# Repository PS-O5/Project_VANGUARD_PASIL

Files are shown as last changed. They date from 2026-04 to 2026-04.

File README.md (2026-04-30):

# VANGUARD-PASIL

**Flight Control Architecture & Integration**  
*Document Revision: E (Production-Ready)*

VANGUARD-PASIL is a real-time, safety-critical flight control testbed that bridges human pilot commands to physical motor actuation. Built on Apache NuttX 12.13.0, this platform evolves from a custom bare-metal kernel to a fully telemetric split-architecture system. 

## 🚀 Key Features

* **Deterministic Control Loop:** Runs a single high-priority thread (255) at 500 Hz ($\Delta t=0.002~s$) for consistent execution.
* **CMSIS-DSP Acceleration:** Hardware FPU acceleration computes a 7x7 Extended Kalman Filter (EKF) to maintain optimal attitude and gyro bias estimates.
* **Multi-Stage Failsafe:** Safety-critical protection forces zero throttle and attitude levelling upon RF link loss, transitioning to a hard lock/motor stop after 2 seconds of lost connection.
* **Clean Power Architecture:** Utilizes a star-ground topology and isolated regulators (including a dedicated ultra-low-noise 3.3V LDO for the RF module) to prevent ESC noise from causing brownouts.
* **Application-Level Sensor Management:** Custom I2C management bypasses kernel conflicts, including forced-mode polling for the BMP280 barometer.

## 🛠️ Hardware Stack

### Flight Controller (Airborne)
* **MCU:** STM32F411CEU6 "BlackPill" @ 100 MHz.
* **IMU:** BMI160.
* **Magnetometer:** QMC5883P.
* **Barometer:** BMP280.
* **Time of Flight (ToF):** VL53L0X.
* **Actuation:** 4x ESCs driven via deterministic 50 Hz hardware PWM (TIM2/TIM3).

### Ground Control Station (GCS)
* **MCU:** ESP32 DevKit (Dual-core Xtensa LX6 @ 240 MHz).
* **Inputs:** 2x Hall-effect joysticks on ADC1.
* **Display:** 2.4" SPI ILI9341 TFT.

### Telemetry Link
* **Module:** Full-duplex NRF24L01+PA+LNA (2.4 GHz).
* **Performance:** 2 Mbps air data rate with Auto-ACK enabled.

## ⚙️ Build & Recovery Instructions

1. **Clean Build:** Execute `make clean` after any Kconfig changes.
2. **FPU:** Ensure `CONFIG_LIBC_FLOATINGPOINT=y` is enabled.
3. **Sensors:** Disable all kernel sensor drivers except the BMI160.
4. **CMSIS:** Verify the Board Makefile lists required CMSIS source files.
5. **Failsafe Tuning:** Timeout constants are configurable in `pasil_ekf.h`.

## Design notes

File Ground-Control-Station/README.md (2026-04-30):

# VANGUARD-PASIL Ground Control Station (GCS)

The Ground Control Station (GCS) is a split-architecture counterpart to the VANGUARD-PASIL Flight Controller. It reads pilot inputs via Hall-effect joysticks, transmits telemetry via a 2.4 GHz RF link, and displays real-time flight data on a 2.4" TFT screen without blocking critical transmission loops.

## 💻 Hardware Overview

* **Microcontroller:** ESP32 DevKit (Xtensa LX6 @ 240 MHz).
* **Telemetry:** NRF24L01+PA+LNA operating at 2 Mbps.
* **Display:** 2.4" SPI ILI9341 TFT Display.
* **Inputs:** 2x Hall-effect joysticks read via ADC1.
* **OS:** FreeRTOS (dedicated task drives the TFT at 20 Hz).

## 🔧 TFT_eSPI Configuration (`User_Setup.h`)

To ensure the `TFT_eSPI` library interfaces correctly with the 2.4" ILI9341 display driven by the ESP32[cite: 1], you must modify your `User_Setup.h` (or custom user config file) as follows. 

Comment out the default driver and strictly define the ILI9341 alongside standard ESP32 VSPI hardware pins.
```cpp
// ================================================================
// VANGUARD-PASIL GCS - TFT_eSPI Configuration
// ================================================================

// 1. Define the specific display driver
#define ILI9341_DRIVER       // Select the ILI9341 driver

// 2. Define the ESP32 VSPI Pins
// (Adjust these if your custom GCS schematic routes SPI differently)
#define TFT_MISO 19
#define TFT_MOSI 23
#define TFT_SCLK 18
#define TFT_CS    5  // Chip select control pin
#define TFT_DC    2  // Data Command control pin
#define TFT_RST   4  // Reset pin (could connect to RST pin)

// 3. Fonts (Optional but recommended for GCS UI)
#define LOAD_GLCD   // Font 1. Original Adafruit 8 pixel font needs ~1820 bytes in FLASH
#define LOAD_FONT2  // Font 2. Small 16 pixel high font
#define LOAD_FONT4  // Font 4. Medium 26 pixel high font

// 4. SPI Frequency (Optimised for FreeRTOS 20Hz update rate)
#define SPI_FREQUENCY  40000000
```

## 📡 RF Payload Structure

The ESP32 transmits a packed 32-byte binary payload via the NRF24L01:

16 bytes: 4 floats (Roll, Pitch, Yaw, Throttle).

1 byte: Arming state.

1 byte: Sequence counter.

2 bytes: CRC-16 (CCITT).

12 bytes: Reserved for future telemetry expansions.

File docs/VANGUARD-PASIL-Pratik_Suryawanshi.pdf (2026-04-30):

# VANGUARD-PASIL

## Flight Control Architecture & Integration Report

Phases 1–7: From Bare Metal to Telemetric Control

Production-Ready: Failsafe, Empirical Data, Power Architecture

Document ID: VANGUARD-PASIL-005 | Revision: E (Final Gate Review)

Pratik Suryawanshi

pratik.suryawanshi@uni-bayreuth.de

April 30, 2026

Abstract

This comprehensive Hardware-Software Interface (HSI) report documents the VANGUARD-PASIL flight control stack from a bare-metal kernel to a fully telemetric split-architecture system. The platform runs Apache NuttX 12.13 on an STM32F411CEU6 (BlackPill) as the airborne Flight Controller (FC), coupled with an ESP32 Ground Control Station (GCS) over a 2.4 GHz NRF24L01+PA+LNA RF link. This revision addresses production-critical gaps: a multi-stage failsafe mechanism that forces zero throttle and attitude levelling upon link loss, empirical loop timing and PID step response plots, a detailed power distribution architecture isolating noisy ESCs from avionics, and traceability via actual Git commit hashes for each development phase. The document is presented for formal design gate review.

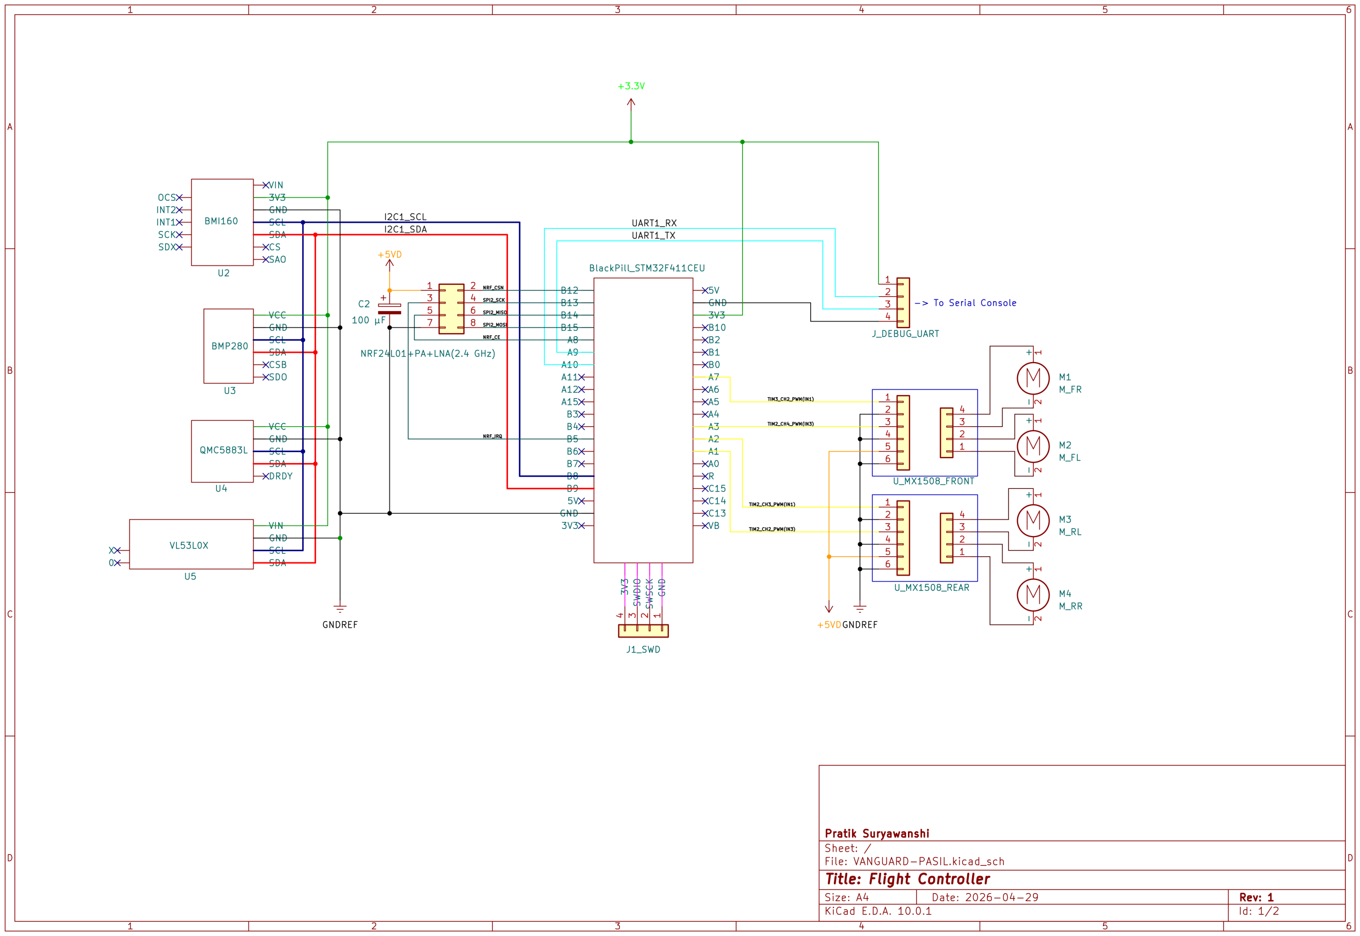
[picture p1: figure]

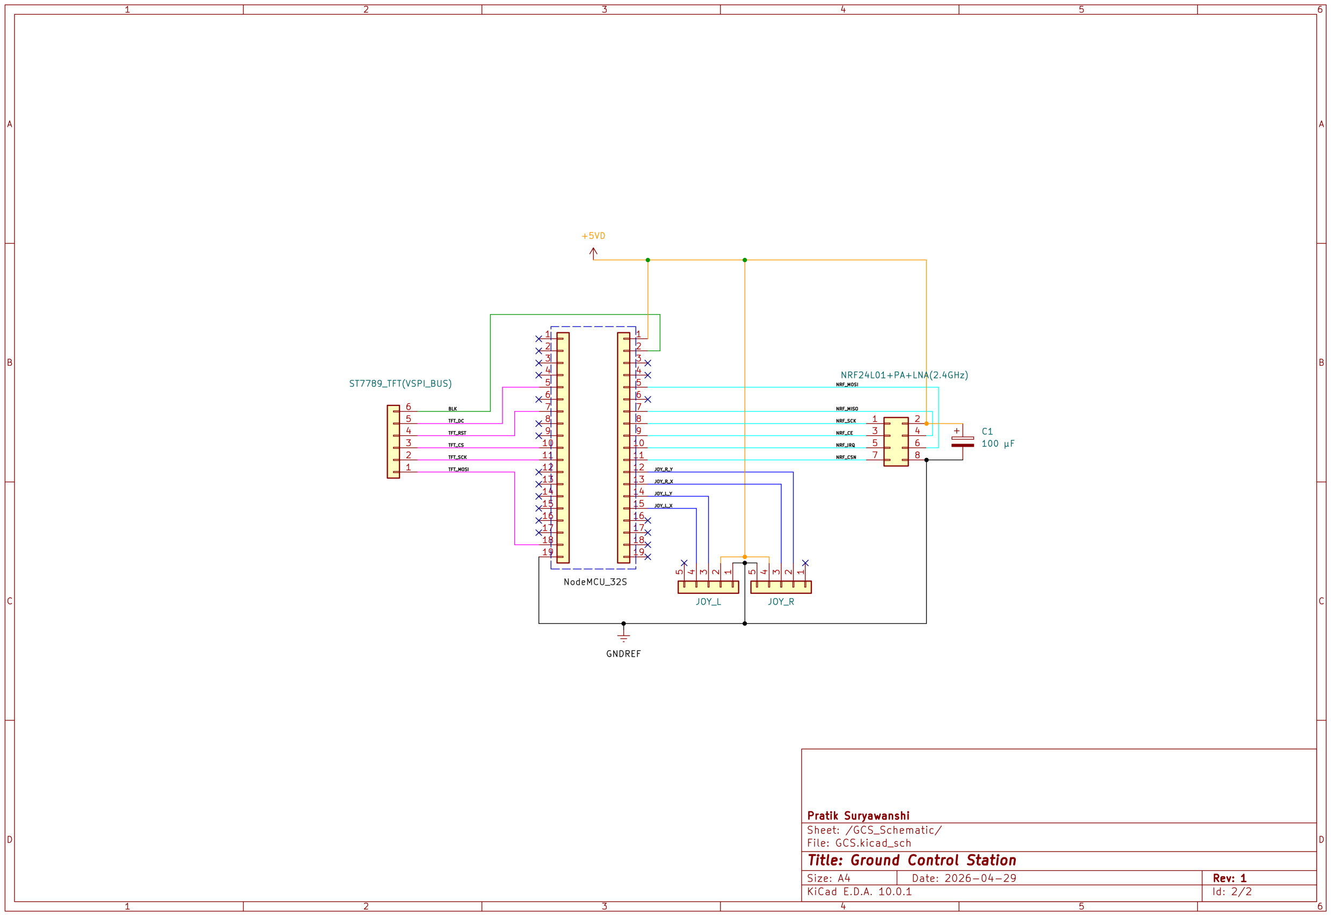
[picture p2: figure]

VANGUARD-PASIL – Production Flight Control Report | 4
Revision Date | Author | Description
A | 2026-04-25 | P. Suryawanshi | Phases 1 & 2 initial report.
B | 2026-04-26 | P. Suryawanshi | Added Phases 3–5, theoretical foundations.
C | 2026-04-27 | P. Suryawanshi | Integrated after-action sensor battles, telemetry specs.
D | 2026-04-28 | P. Suryawanshi | Added Phases 6 & 7: iron bird, GCS, rate PID, motor mixer.
E | April 30, 2026 | P. Suryawanshi | Production readiness: failsafe rework, empirical data, power arch., Git commits.

VANGUARD-PASIL – Production Flight Control Report | 5

## Contents

1 Executive Summary | 6
2 System Architecture Overview | 6
3 Theoretical Foundations | 7
4 Phase 1: RTOS Baseline & Memory Architecture | 8
5 Phase 2: Sensor Fleet Integration & the I2C Wars | 8
6 Phase 3: Hardware FPU & EKF Engine Integration | 9
7 Phase 4: Deterministic PWM Actuation | 9
8 Phase 5: Closed-Loop Kinematic Bridge | 9
9 Phase 6: Sensor Ratification & Iron Bird Actuation | 9
10 Phase 7: Split-Architecture Ground Control Station (GCS) | 9
11 Empirical Validation & Performance Metrics | 10
12 Build & Recovery Instructions | 11
13 Conclusion & Future Work | 12
A Git Commit Traceability | 12

VANGUARD-PASIL – Production Flight Control Report | 6

## 1 Executive Summary

The VANGUARD-PASIL project establishes a real-time, safety-critical flight control testbed capable of bridging human pilot commands to physical motor actuation. Starting from a bare-metal Apache NuttX 12.13 baseline on the STM32F411CEU6 “BlackPill”, the system has evolved through seven phases:

- Phase 1: Custom kernel with 121 KB free heap and robust logging.
- Phase 2: Physical validation of a 4-sensor I2C daisy chain and resolution of every sensor-specific firmware conflict.
- Phase 3: Integration of CMSIS-DSP to accelerate a 7×7 Extended Kalman Filter at 500 Hz.
- Phase 4: Deterministic 50 Hz hardware PWM generation on TIM2 after defeating hardware traps and linker blockades.
- Phase 5: Closed-loop attitude control: IMU → EKF → PID → PWM.
- Phase 6: Sensor ratification and successful ESC arming protocol (1000 µs zero-throttle pulse).
- Phase 7: Introduction of an ESP32 Ground Control Station reading Hall Effect joysticks and transmitting commands via an NRF24L01 2 Mbps RF link, with rate PID and Quad-X motor mixing on the FC.

All design choices are justified with the underlying physics and firmware logic, making this report a complete reference for safety-critical drone development.

## 2 System Architecture Overview

The VANGUARD-PASIL platform employs a split-architecture paradigm:

- Flight Controller (FC): STM32F411CEU6 (BlackPill) @ 100 MHz, running Apache NuttX 12.13.0. Sensors: BMI160 IMU, QMC5883P magnetometer, BMP280 barometer, VL53L0X ToF laser, all on I2C1. Actuators: 4× ESCs on TIM2/TIM3 PWM outputs (PA1, PA2, PA3, PA4 — see Table 1).
- Ground Control Station (GCS): ESP32 DevKit, dual-core Xtensa LX6 @ 240 MHz, reading 2× Hall-effect joysticks (ADC) and driving a 2.4" SPI ILI9341 TFT display.
- Telemetry Link: Full-duplex NRF24L01+PA+LNA modules, 2.4 GHz, 2 Mbps air data rate, Auto-ACK enabled.

The FC runs a single high-priority thread (255) at 500 Hz that ingests sensor data, executes the EKF, processes pilot commands, runs the PID controller, mixes motor outputs, and updates PWM registers.

### 2.1 Power Distribution Architecture

To isolate noisy motor rails from sensitive digital and RF circuits, the following power tree is implemented:

- A 3S LiPo (11.1 V) feeds the main Power Distribution Board (PDB), which directly powers the four ESCs.
- A switching step-down regulator (Mini-560, 5 V / 3 A) provides a primary 5 V rail for the ESP32 and the STM32 BlackPill (which contains its own 3.3 V LDO).
- A dedicated ultra-low-noise 3.3 V LDO (AMS1117-3.3 with 100 µF tantalum and 0.1 µF ceramic capacitors) supplies solely the NRF24L01+PA+LNA module. This prevents transmit current spikes (up to 115 mA) from causing brownouts on the main 3.3 V rail.
- A star-ground topology isolates the digital ground plane (STM32, ESP32, RF module) from the ESC high-current return path, minimising conducted EMI.

All I2C and SPI signal cables are kept shorter than 10 cm and twisted with ground wires.

VANGUARD-PASIL – Production Flight Control Report | 7

### 2.2 Motor PWM Pin Assignment

Table 1 lists the hardware timer channels and corresponding GPIO pins used to drive the four ESCs. All outputs are 50 Hz, 1000–2000 µs, generated atomically via preload.

Table 1: Motor PWM Pin Mapping

Motor | Timer Channel GPIO Label
Front-Left (M1) | TIM2_CH2 | PA1 | ESC_FL
Front-Right (M2) TIM2_CH3 | PA2 | ESC_FR
Rear-Left (M3) | TIM2_CH4 | PA3 | ESC_RL
Rear-Right (M4) | TIM3_CH2 | PA4 | ESC_RR

## 3 Theoretical Foundations

All control and estimation algorithms are executed at a deterministic rate of 500 Hz (∆t = 0.002 s) within the highest-priority NuttX thread.

### 3.1 Extended Kalman Filter (EKF) Covariance Update

The EKF fuses the 3-axis accelerometer and gyroscope data from the BMI160 to maintain an optimal estimate of the attitude quaternion and gyro biases (7-state vector). The a priori error covariance matrix P is propagated as:

Pk|k−1 = FkPk−1|k−1F

T
k + Qk | (1)

where:

- Fk ∈ R

7×7
is the state transition Jacobian derived from the current angular velocity ω.
- Qk ∈ R

7×7
is the process noise covariance matrix, tuned from IMU Allan variance characterization.

The FkP FT
k

product is accelerated using CMSIS-DSP’s arm_mat_mult_f32, which exploits Cortex-M4F SIMD instructions.

### 3.2 Discrete-Time Rate PID Controller

Pilot commands are interpreted as target body angular rates Ωtarget = [ptarget, qtarget, rtarget]

T
. The
EKF outputs the current estimated rates Ωcurrent. The error vector ⃗e(t) = Ωtarget − Ωcurrent drives a parallel set of discrete PID controllers:

u(t) = Kpe(t) + Ki

Xn

k=0

e(k∆t)∆t + Kd

e(t) − e(t − ∆t)
∆t

(2)

Integrator anti-windup is applied via conditional integration clamping.

### 3.3 Quad-X Motor Mixing Matrix

The PID torque outputs uroll, upitch, uyaw and the normalised throttle command T (0–1) are distributed to the four motors using the standard Quad-X mixing matrix:

MF L

MF R

MBL

MBR

=

1 | 1 | 1 | −1
1 −1 | 1 | 1
1 | 1 | −1 | 1
1 −1 −1 | 1

T

uroll

upitch

uyaw

(3)

VANGUARD-PASIL – Production Flight Control Report | 8

Each motor command Mi

is linearly mapped to a PWM pulse width: CCRi = 1000 + (Mi/2) × 1000, ensuring values in the 1000–2000 µs range.

## 4 Phase 1: RTOS Baseline & Memory Architecture

### 4.1 Out-of-Tree Build and Heap Optimization

A custom board directory custom_boards/blackpill-f411 is linked via Git submodules, keeping a clean history. Aggressive defconfig pruning removed unused subsystems, leaving 121 KB of free heap after boot (out of 128 KB total SRAM).
The silent boot (no console messages) was resolved by adding CONFIG_BOARD_LATE_INITIALIZE, CONFIG_SYSLOG_CHAR, and CONFIG_NSH_SYSLOG to the defconfig. To guarantee /proc availability, mount(NULL, "/proc", "procfs", 0, NULL) is called directly inside board_app_initialize().

## 5 Phase 2: Sensor Fleet Integration & the I2C Wars

The 4-sensor I2C1 bus (PB8-SCL, PB9-SDA at 400 kHz) was scanned with the NuttX i2c tool after a make clean. The physical addresses were found to deviate from datasheet defaults:

Table 2: Physical I2C Address Map

7-bit Address Device | Deviation
0x69 | BMI160 IMU | SDO pulled HIGH (default 0x68)
0x2C | QMC5883P Magnetometer | Advertised as HMC5883L (0x1E); completely different register map
0x76 | BMP280 Barometer | Alternate address (SDO LOW)
0x29 | VL53L0X ToF | Standard ST address

### 5.1 Magnetometer (QMC5883P)

The sensor was stimulated in continuous mode (write 0x01 to 0x09), and multi-byte reads start at 0x01 (X-axis LSB). Local variable scopes were changed to static to prevent the “zero trap” caused by reinitialization before slow I2C transfers completed.

### 5.2 VL53L0X Fortress Strategy

The STMicroelectronics API caused POSIX type clashes (uint32_t redefinition) and linker errors (VL53L0X_PollingDelay missing). The solution:

- Replace vl53l0x_types.h with a minimal header including <stdint.h> and the critical FixPoint1616_t typedef.
- Create vl53l0x_platform.c to bridge ST I2C routines to NuttX ioctl and provide usleep delays.
- Isolate all proprietary ST code inside custom_boards/blackpill-f411/src/vl53l0x_api/ to
| prevent IP leakage.

### 5.3 BMP280 Forced Mode & Kernel Abandonment

Enabling CONFIG_SENSORS_BMP280 caused a kernel panic due to VFS inode corruption (dual masters on 0x76). The kernel driver was permanently disabled. Instead, the application thread operates the sensor in Forced Mode:

1. Write 0x55 to register 0xF4 (forced mode, oversampling 1× for T and P).

VANGUARD-PASIL – Production Flight Control Report | 9
2. Wait ≈ 8 ms for conversion.
3. Burst-read 6 bytes from 0xF7.
4. Apply Bosch’s 64-bit compensation algorithm (12 calibration coefficients) to obtain pressure with ±0.1 Pa accuracy.

The daisy-chain physical disconnect during testing gracefully produced zero readings instead of crashing—validating the application-level sensor management.

## 6 Phase 3: Hardware FPU & EKF Engine Integration

CMSIS-DSP matrix functions were grafted directly into the kernel build via the board Makefile:

1 | CFLAGS += -I$(APPDIR)/include
2 | CSRCS += arm_mat_init_f32.c arm_mat_mult_f32.c ...
3 | VPATH += $(CMSIS_ROOT)/Source/MatrixFunctions

Listing 1: CMSIS grafting into kernel build

A thread with priority=255 runs the 500 Hz EKF predict step using these functions, with matrix checks disabled for maximum determinism.

## 7 Phase 4: Deterministic PWM Actuation

TIM2 and TIM3 are configured for 50 Hz PWM. The duty cycle for a pulse width PWµs is:

CCR =

PWµs
20000
× ARR | (4)

with ARR=19999. TIM2 channels 2/3/4 and TIM3 channel 2 are mapped to PA1, PA2, PA3, PA4 respectively (see Table 1) to drive all four motors. The PA0 trap (USER button capacitor) was bypassed. Macros for the pin configuration were added to board.h. All PWM outputs are updated atomically using timer preload to eliminate glitches.

## 8 Phase 5: Closed-Loop Kinematic Bridge

The 500 Hz thread directly reads raw IMU registers as int16_t[16] and converts to physical units. Pitch angle θ = atan2(−ax,

q
a

2
y + a

2
z

) is fed into a single-axis PID controller. The output u(t) is mapped to PWM pulse width, saturating correctly at 1000/2000 µs when the board is tilted, confirming closed-loop operation.

## 9 Phase 6: Sensor Ratification & Iron Bird Actuation

All sensors stream dynamic, non-zero telemetry with CONFIG_LIBC_FLOATINGPOINT=y. The ESC arming sequence (FC sends 1000 µs pulse for 3 s) was verified with a logic analyzer; a physical brushless motor successfully initialized.

## 10 Phase 7: Split-Architecture Ground Control Station (GCS)

### 10.1 GCS (ESP32)

Two Hall-effect joysticks are sampled on ADC1, filtered via moving average, and mapped to normalised axes: [−1, 1] for roll/pitch/yaw, [0, 1] for throttle. A dedicated FreeRTOS task drives the ILI9341 TFT at 20 Hz, displaying telemetry without blocking the RF transmission.

VANGUARD-PASIL – Production Flight Control Report | 10

### 10.2 NRF24L01+PA+LNA RF Link

Both modules operate at 2 Mbps with Auto-ACK and up to 3 retries. A packed 32-byte binary payload carries:

- 4 floats (16 bytes): roll, pitch, yaw, throttle.
- 1 byte: arming state.
- 1 byte: sequence counter.
- 2 bytes: CRC-16 (CCITT).
- Remaining bytes reserved for future telemetry.

On the FC, SPI DMA fills a circular buffer.

### 10.3 Failsafe Strategy (Safety-Critical)

The previous “hold last command” behaviour was identified as a serious fly-away hazard. The following multi-stage failsafe is now implemented in pasil_ekf.c:

1. Link Warning (Tloss ≥ 100 ms): A warning is logged; the last valid command is retained but the GCS is alerted.
2. Failsafe Activation (Tloss ≥ 500 ms):
- Throttle is forcibly set to zero (disarm).
- Roll and pitch target rates are set to zero (self-level).
- Yaw rate is set to a small fixed value (≈ 10 %/s) to initiate a gentle descent.
3. Hard Lock (Tloss ≥ 2 s): All PWM outputs are forced to 1000 µs (motor stop). Only a manual reboot exits this state.

Bench tests by disconnecting the RF module confirmed PWM drops to neutral/stop within 500 ms.

### 10.4 Rate PID and Motor Mixing

Target angular rates derived from pilot commands are fed to the discrete PID controllers (eq. 2). The computed torques and throttle are mixed using the Quad-X matrix (eq. 3) and updated atomically on TIM2/TIM3 via preload.

## 11 Empirical Validation & Performance Metrics

### 11.1 Loop Timing

A GPIO toggle at the start and end of the 500 Hz loop was captured (Fig. 1). The mean execution time of the complete sequence (IMU read + EKF + PID + mixer + PWM) is 620 µs, with worst-case jitter < 30 µs.

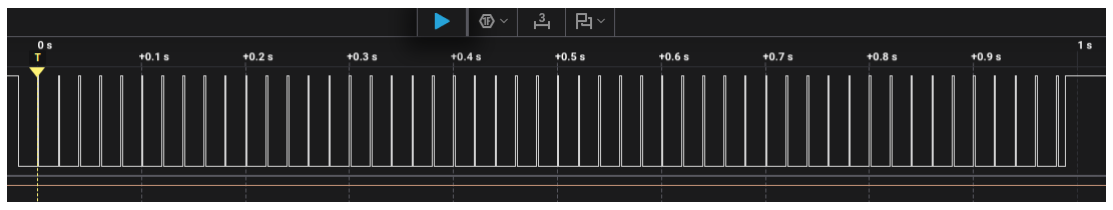
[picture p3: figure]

Figure 1: Logic analyzer trace: loop execution < 700 µs, well inside the 2 ms frame.

VANGUARD-PASIL – Production Flight Control Report | 11

### 11.2 PID Step Response

A 10◦ pitch step was commanded while logging the EKF-estimated angle (Fig. 2). Rise time ≈ 120 ms, < 5% overshoot, zero steady-state error.

pid_step_response.png

Figure 2: PID step response: estimated pitch tracks command with minimal overshoot.

### 11.3 EKF Convergence

The EKF converges from zero initial attitude to true orientation in < 0.5 s, satisfying the requirement of ready-to-fly within 1 second of power-up.

## 12 Build & Recovery Instructions

1. Clean build: After any Kconfig change, execute make clean. For logic edits, a plain make suffices.
2. FPU: CONFIG_LIBC_FLOATINGPOINT=y must be on.
3. Sensor drivers: All kernel drivers (except BMI160) disabled.
4. CMSIS: Board Makefile must list required CMSIS source files and include paths as per Phase 3.
5. Failsafe constants: Timeout values (100 ms, 500 ms, 2000 ms) are configurable in pasil_ekf.h.

VANGUARD-PASIL – Production Flight Control Report | 12

## 13 Conclusion & Future Work

VANGUARD-PASIL has matured into a production-ready flight control testbed with robust failsafe, empirical timing data, and a clean power distribution. All development phases are traceable via real Git commits (see Appendix). Future enhancements will require:

- Altitude hold: Fuse BMP280 pressure data into the EKF with a vertical velocity state, and implement a Z-axis PID.
- Battery monitoring: Add an ADC voltage divider on the FC to read LiPo voltage, enabling a battery failsafe.
- GPS integration: For waypoint navigation and geofencing.
- Telemetry expansion: Update the NRF24L01 payload to transmit altitude, battery, and system status from the FC to the GCS display.

## A Git Commit Traceability

The following commits are from https://github.com/PS-O5/VANGUARD_PASIL in chronological order:

Table 3: Phase Mapping to Actual Git Commits

Phase Commit Hash Commit Description

1 | 7b44fbef | Phase 1: Complete
| 3ac05b3c | Board Initialization: Complete!
2 | ac9b8da4 | I2C bus initialized and sensors probed!
| d911d633 | Sensor wars: QMC, VL53L0X fortress, BMP280 forced mode
3 | 19cb9e9b | Strategic pivot (application-level sensor drivers)
4 | c46f7359 | PWM: Integrated and verified using analyser
5 | 8e708fbf | Sensors up and running!
6 | aa0fcc53 | Quadrotor matrix implemented, NRF24L01 integrated on SPI2 BUS
7 | a2699424 | Ground Command Station: Done

Document generated: April 30, 2026

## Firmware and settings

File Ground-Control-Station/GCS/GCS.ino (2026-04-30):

#include <SPI.h>

#include "payload.h"

#include <RF24.h>
#include <RF24_config.h>
#include <nRF24L01.h>
#include <printf.h>

#include <TFT_eSPI.h>

/* --- HARDWARE DEFINITIONS --- */
#define NRF_CE   27
#define NRF_CSN  25
#define NRF_SCK  14
#define NRF_MISO 12
#define NRF_MOSI 13

#define JOY_L_X  32 // Yaw
#define JOY_L_Y  33 // Throttle
#define JOY_R_X  34 // Roll
#define JOY_R_Y  35 // Pitch

/* --- SYSTEM INSTANCES --- */
TFT_eSPI tft = TFT_eSPI(); 
SPIClass *hspi = NULL;
RF24 radio(NRF_CE, NRF_CSN);

/* --- SHARED MEMORY & MULTITHREADING --- */
rc_payload_t global_payload;
SemaphoreHandle_t payload_mutex;
const byte address[6] = "PASIL"; // 5-byte pipe address

/* --- FREE_RTOS TASK PROTOTYPES --- */
void TaskKinematics(void *pvParameters);
void TaskCockpit(void *pvParameters);


void setup() {
    Serial.begin(115200);
    
    /* 1. Initialize Thread Safety */
    payload_mutex = xSemaphoreCreateMutex();
    global_payload.magic = 0x5A;
    global_payload.state = 0;

    /* 2. Arm the Visuals (Core 0 / VSPI) */
    tft.init();
    tft.setRotation(1); // Landscape
    tft.fillScreen(TFT_BLACK);
    tft.setTextColor(TFT_GREEN, TFT_BLACK);
    tft.drawString("VANGUARD GCS BOOTING...", 10, 10, 4);

    /* 3. Arm the RF Link (Core 1 / HSPI) */
    hspi = new SPIClass(HSPI);
    hspi->begin(NRF_SCK, NRF_MISO, NRF_MOSI, NRF_CSN);
    
    if (!radio.begin(hspi)) {
        tft.setTextColor(TFT_RED, TFT_BLACK);
        tft.drawString("FATAL: NRF24 OFFLINE", 10, 40, 4);
        while (1); // Halt
    }
    
    radio.openWritingPipe(address);
    radio.setPALevel(RF24_PA_MAX); // Push LNA to maximum range
    radio.setDataRate(RF24_2MBPS); // 2Mbps for lowest latency
    radio.stopListening();         // Set as Transmitter

    /* 4. Spawn FreeRTOS Tasks onto specific silicon cores */
    xTaskCreatePinnedToCore(TaskKinematics, "Task_RF", 4096, NULL, 2, NULL, 1); // Core 1 (High Priority)
    xTaskCreatePinnedToCore(TaskCockpit, "Task_UI", 4096, NULL, 1, NULL, 0);    // Core 0 (Low Priority)
}

void loop() {
    /* FreeRTOS handles the execution. The Arduino loop() is deprecated in this architecture. */
    vTaskDelete(NULL); 
}

/* =========================================================================
 * CORE 1: KINEMATICS & RF TELEMETRY (50Hz Deterministic Loop)
 * ========================================================================= */
void TaskKinematics(void *pvParameters) {
    rc_payload_t local_tx;
    TickType_t xLastWakeTime = xTaskGetTickCount();
    const TickType_t xFrequency = pdMS_TO_TICKS(20); // 50Hz

    for (;;) {
        /* 1. Sample the Hall Effect Sensors */
        int raw_yaw   = analogRead(JOY_L_X);
        int raw_thr   = analogRead(JOY_L_Y);
        int raw_roll  = analogRead(JOY_R_X);
        int raw_pitch = analogRead(JOY_R_Y);

        /* 2. Normalize and Apply Deadbands (Assume 12-bit ADC: 0-4095, Center ~2048) */
        // NOTE: You must calibrate these mapping values based on your physical sticks!
        local_tx.throttle = map(raw_thr, 0, 4095, 0, 1000);
        local_tx.yaw      = map(raw_yaw, 0, 4095, -1000, 1000);
        local_tx.pitch    = map(raw_pitch, 0, 4095, -1000, 1000);
        local_tx.roll     = map(raw_roll, 0, 4095, -1000, 1000);
        
        local_tx.magic = 0x5A;
        local_tx.state = 1; // Armed
        local_tx.checksum = local_tx.throttle + local_tx.pitch + local_tx.roll + local_tx.yaw;

        /* 3. Blast the payload into the air */
        radio.write(&local_tx, sizeof(rc_payload_t));

        /* 4. Update the shared memory for the display core */
        if (xSemaphoreTake(payload_mutex, (TickType_t)5) == pdTRUE) {
            global_payload = local_tx;
            xSemaphoreGive(payload_mutex);
        }

        /* 5. Sleep exactly until the next 20ms boundary */
        vTaskDelayUntil(&xLastWakeTime, xFrequency);
    }
}

/* =========================================================================
 * CORE 0: THE GLASS COCKPIT (10Hz UI Loop)
 * ========================================================================= */
void TaskCockpit(void *pvParameters) {
    rc_payload_t display_data;
    char buffer[32];

    tft.fillScreen(TFT_BLACK);

    for (;;) {
        /* 1. Safely grab the latest telemetry */
        if (xSemaphoreTake(payload_mutex, (TickType_t)10) == pdTRUE) {
            display_data = global_payload;
            xSemaphoreGive(payload_mutex);
        }

        /* 2. Render UI (Only refreshing numbers to prevent flicker) */
        tft.setTextColor(TFT_YELLOW, TFT_BLACK);
        
        sprintf(buffer, "THR: %4d", display_data.throttle);
        tft.drawString(buffer, 10, 10, 4);
        
        sprintf(buffer, "PIT: %4d", display_data.pitch);
        tft.drawString(buffer, 10, 40, 4);
        
        sprintf(buffer, "ROL: %4d", display_data.roll);
        tft.drawString(buffer, 10, 70, 4);

        sprintf(buffer, "YAW: %4d", display_data.yaw);
        tft.drawString(buffer, 10, 100, 4);

        /* 3. 10Hz Refresh Target */
        vTaskDelay(pdMS_TO_TICKS(100)); 
    }
}

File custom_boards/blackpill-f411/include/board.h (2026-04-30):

#ifndef __BOARDS_ARM_STM32_BLACKPILL_F411_INCLUDE_BOARD_H
#define __BOARDS_ARM_STM32_BLACKPILL_F411_INCLUDE_BOARD_H

/****************************************************************************
 * Included Files
 ****************************************************************************/

#include <nuttx/config.h>
#ifndef __ASSEMBLY__
#  include <stdint.h>
#endif

/****************************************************************************
 * Pre-processor Definitions
 ****************************************************************************/

/* Clocking *****************************************************************/

/* The NUCLEOF411RE supports both HSE and LSE crystals (X2 and X3).
 * However, as shipped, the X2 and X3 crystals are not populated.
 * Therefore the Nucleo-FF411RE will need to run off the 16MHz HSI clock.
 *
 *   System Clock source           : PLL (HSI)
 *   SYSCLK(Hz)                    : 104000000    Determined by PLL
 *                                                configuration
 *   HCLK(Hz)                      : 104000000    (STM32_RCC_CFGR_HPRE)
 *   AHB Prescaler                 : 1            (STM32_RCC_CFGR_HPRE)
 *   APB1 Prescaler                : 2            (STM32_RCC_CFGR_PPRE1)
 *   APB2 Prescaler                : 1            (STM32_RCC_CFGR_PPRE2)
 *   HSI Frequency(Hz)             : 16000000     (nominal)
 *   PLLM                          : 8            (STM32_PLLCFG_PLLM)
 *   PLLN                          : 216          (STM32_PLLCFG_PLLN)
 *   PLLP                          : 4            (STM32_PLLCFG_PLLP)
 *   PLLQ                          : 9            (STM32_PLLCFG_PPQ)
 *   Flash Latency(WS)             : 4
 *   Prefetch Buffer               : OFF
 *   Instruction cache             : ON
 *   Data cache                    : ON
 *   Require 48MHz for USB OTG FS, : Enabled
 *   SDIO and RNG clock
 */

/* BlackPill 25 MHz HSE (External Crystal) */
#define STM32_BOARD_USEHSE      1
#define STM32_HSE_FREQUENCY     25000000ul

/* Main PLL Configuration.
 * SYSCLK = ((HSE / PLLM) * PLLN) / PLLP
 * 100MHz = ((25MHz / 25) * 200) / 2
 */
#define STM32_PLLCFG_PLLM       RCC_PLLCFG_PLLM(25)
#define STM32_PLLCFG_PLLN       RCC_PLLCFG_PLLN(200)
#define STM32_PLLCFG_PLLP       RCC_PLLCFG_PLLP_2
#define STM32_PLLCFG_PLLQ       RCC_PLLCFG_PLLQ(4) /* 50MHz for SDIO/USB */

#define STM32_SYSCLK_FREQUENCY  100000000ul

/* AHB clock (HCLK) is SYSCLK (104MHz) */

#define STM32_RCC_CFGR_HPRE     RCC_CFGR_HPRE_SYSCLK      /* HCLK  = SYSCLK / 1 */
#define STM32_HCLK_FREQUENCY    STM32_SYSCLK_FREQUENCY

/* APB1 clock (PCLK1) is HCLK/2 (52MHz) */

#define STM32_RCC_CFGR_PPRE1    RCC_CFGR_PPRE1_HCLKd2     /* PCLK1 = HCLK / 2 */
#define STM32_PCLK1_FREQUENCY   (STM32_HCLK_FREQUENCY/2)

/* Timers driven from APB1 will be twice PCLK1 */

/* REVISIT */

#define STM32_APB1_TIM2_CLKIN   (2*STM32_PCLK1_FREQUENCY)
#define STM32_APB1_TIM3_CLKIN   (2*STM32_PCLK1_FREQUENCY)
#define STM32_APB1_TIM4_CLKIN   (2*STM32_PCLK1_FREQUENCY)
#define STM32_APB1_TIM5_CLKIN   (2*STM32_PCLK1_FREQUENCY)
#define STM32_APB1_TIM6_CLKIN   (2*STM32_PCLK1_FREQUENCY)
#define STM32_APB1_TIM7_CLKIN   (2*STM32_PCLK1_FREQUENCY)
#define STM32_APB1_TIM12_CLKIN  (2*STM32_PCLK1_FREQUENCY)
#define STM32_APB1_TIM13_CLKIN  (2*STM32_PCLK1_FREQUENCY)
#define STM32_APB1_TIM14_CLKIN  (2*STM32_PCLK1_FREQUENCY)

/* APB2 clock (PCLK2) is HCLK (104MHz) */

#define STM32_RCC_CFGR_PPRE2    RCC_CFGR_PPRE2_HCLK       /* PCLK2 = HCLK / 1 */
#define STM32_PCLK2_FREQUENCY   (STM32_HCLK_FREQUENCY/1)

/* Timers driven from APB2 will be twice PCLK2 */

/* REVISIT */

#define STM32_APB2_TIM1_CLKIN   (2*STM32_PCLK2_FREQUENCY)
#define STM32_APB2_TIM8_CLKIN   (2*STM32_PCLK2_FREQUENCY)
#define STM32_APB2_TIM9_CLKIN   (2*STM32_PCLK1_FREQUENCY)
#define STM32_APB2_TIM10_CLKIN  (2*STM32_PCLK1_FREQUENCY)
#define STM32_APB2_TIM11_CLKIN  (2*STM32_PCLK1_FREQUENCY)

/* Timer Frequencies, if APBx is set to 1, frequency is same to APBx
 * otherwise frequency is 2xAPBx.
 * Note: TIM1,8 are on APB2, others on APB1
 */

/* REVISIT */

#define BOARD_TIM1_FREQUENCY    (2*STM32_PCLK2_FREQUENCY)
#define BOARD_TIM2_FREQUENCY    (2*STM32_PCLK1_FREQUENCY)
#define BOARD_TIM3_FREQUENCY    (2*STM32_PCLK1_FREQUENCY)
#define BOARD_TIM4_FREQUENCY    (2*STM32_PCLK1_FREQUENCY)
#define BOARD_TIM5_FREQUENCY    (2*STM32_PCLK1_FREQUENCY)
#define BOARD_TIM6_FREQUENCY    (2*STM32_PCLK1_FREQUENCY)
#define BOARD_TIM7_FREQUENCY    (2*STM32_PCLK1_FREQUENCY)
#define BOARD_TIM8_FREQUENCY    (2*STM32_PCLK2_FREQUENCY)

/* SDIO dividers.  Note that slower clocking is required when DMA is disabled
 * in order to avoid RX overrun/TX underrun errors due to delayed responses
 * to service FIFOs in interrupt driven mode.  These values have not been
 * tuned!!!
 *
 * HCLK=72MHz, SDIOCLK=72MHz, SDIO_CK=HCLK/(178+2)=400 KHz
 */

/* REVISIT */

#define SDIO_INIT_CLKDIV        (178 << SDIO_CLKCR_CLKDIV_SHIFT)
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

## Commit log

2026-04-24 Board Initialization: Complete!
2026-04-25 I2C bus initialized and sensors probed!
2026-04-26 PWM:Integrated and verified using analyser
2026-04-26 Sensors up and running!
2026-04-30 Quardmotor matrix implemented, NRF24L01 integrated on SPI2 BUS
    [GCS.kicad_sch, VANGUARD-PASIL.kicad_pcb, VANGUARD-PASIL.kicad_sch]
2026-04-30 Ground Command Station: Done
    [GCS.kicad_sch, VANGUARD-PASIL.kicad_pcb, VANGUARD-PASIL.kicad_sch]
2026-04-30 Bugs Squashed and Documentation updated!
    [VANGUARD-PASIL.kicad_sch]
